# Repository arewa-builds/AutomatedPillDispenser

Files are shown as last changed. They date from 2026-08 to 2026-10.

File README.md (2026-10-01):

# Automated Pill Dispensing & Visual Medication Compliance Monitor

Intelligent, low-cost MedTech station that physically dispenses medication, visually verifies patient presence and pill drop, and tracks adherence risk before missed doses become dangerous.

## Problem

Medication non-adherence costs the healthcare system billions and hits elderly and neurodivergent patients especially hard. This prototype combines a 3D-printed servo carousel, edge computer vision, and Databricks analytics to close that loop non-invasively.

## Architecture

| Layer | Stack | Responsibility |
| :--- | :--- | :--- |
| Embedded | Arduino Nano 33 BLE, MG90S (positional), LiPo + TP4056 | Carousel indexing — 45° per dose, absolute stops |
| Edge CV | Python 3.10+, OpenCV, MediaPipe, PySerial | Face gate + pill contour/color/count |
| Data | Databricks Delta Lake (Bronze → Silver → Gold) | Telemetry ingest & compliance transforms |
| ML / BI | scikit-learn, MLflow, [Databricks dashboard](https://dbc-841e48ce-abec.cloud.databricks.com/dashboardsv3/01f1bc66f608184bb87e728ccb7f308e/published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) | Adherence risk forecast + clinical KPIs |

**Budget:** **$100–$150** (laptop camera preferred) · Timeline **Aug 10 – Sep 20, 2026**.

Published dashboard (SQL warehouse, `pill_dispenser.dashboard_doses` and `pill_dispenser.gold_adherence_7d`): <https://dbc-841e48ce-abec.cloud.databricks.com/dashboardsv3/01f1bc66f608184bb87e728ccb7f308e/published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>

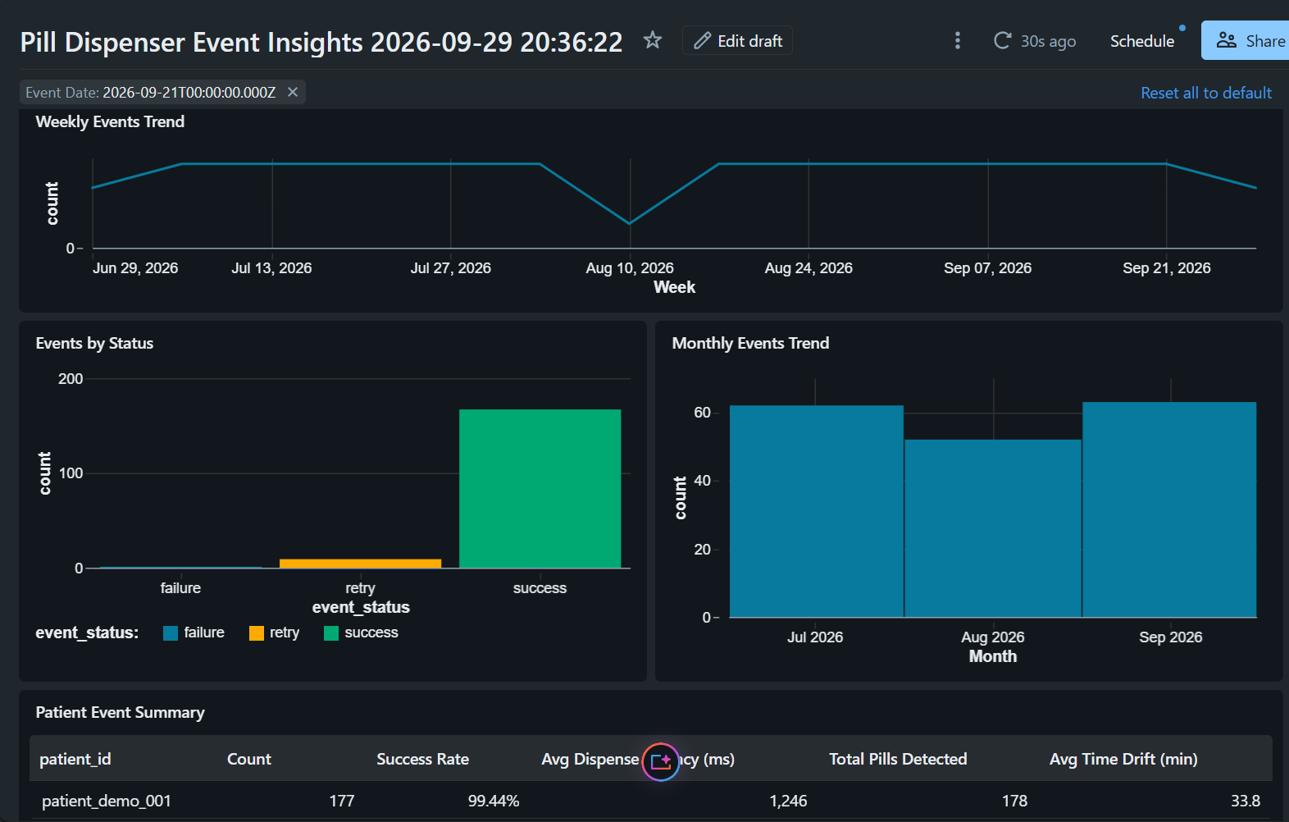
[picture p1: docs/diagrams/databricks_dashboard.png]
Pill Dispenser Event Insights for patient_demo_001: weekly counts dip in the week of 10 Aug, August is lower than July and September, events are mostly success with a few retries, and the summary shows 177 events at 99.44% success


## Repository

```
.cursor/agents/   Expert subagents (systems + CAD)
.cursor/rules/    Always-on project constraints
cad/              OpenSCAD / STL mechanical parts
firmware/         Arduino C++ (Week 1+)
edge/             Python vision + telemetry (Week 2–3)
databricks/       PySpark / Delta Lake (Week 4–5)
ml/               MLflow models (Week 5)
docs/             Schedule, BOM, architecture notes
```

## Cursor expert agents

| Invoke | Role |
| :--- | :--- |
| `/medtech-lead-architect` | Firmware, vision, Databricks, MLflow, Databricks dashboard |
| `/cad-embedded-hardware` | OpenSCAD/STL: carousel, latch, Nano/MG90S/LiPo housing |

See `AGENTS.md` and `cad/README.md`.

## Current status

**Software-first track active** — no Arduino required yet. You can develop vision, mock hardware, telemetry, and local medallion transforms on a laptop now. Firmware is compile-ready for when parts arrive.

## Run now (no hardware)

```bash
# Edge mock pipeline (laptop camera) or headless smoke
cd edge
python3 -m venv .venv; .\.venv\Scripts\Activate.ps1
pip install -r requirements.txt
python pipeline.py --mode mock --headless

# Synthetic Bronze -> Silver -> Gold (local)
cd ../databricks
python3 generate_synthetic_telemetry.py
python3 local_medallion.py
```

See [`docs/software-first-roadmap.md`](docs/software-first-roadmap.md).

## Quick links

- Product brief: [`project.md`](project.md)
- Full schedule & BOM: [`docs/project-context.md`](docs/project-context.md)
- Software-first plan: [`docs/software-first-roadmap.md`](docs/software-first-roadmap.md)
- Edge docs: [`edge/README.md`](edge/README.md)
- Agent guide: [`AGENTS.md`](AGENTS.md)

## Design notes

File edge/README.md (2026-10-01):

# Edge Computer Vision & Telemetry

Python edge stack for face gating, mock/serial dispense, pill verification, and Bronze-ready JSONL logs.

## Docker (project-wide)

From the repo root:

```bash
docker compose build
docker compose run --rm app smoke
docker compose run --rm app edge --mode mock --headless
```

See [`docs/docker.md`](../docs/docker.md). Container installs use `requirements-docker.txt` (`opencv-python-headless`).

## Setup (laptop host venv)

```bash
cd edge
python3 -m venv .venv
# Windows Git Bash: source .venv/Scripts/activate
# Linux/macOS:      source .venv/bin/activate
source .venv/Scripts/activate

# If you previously installed OpenCV 5, remove it first:
pip uninstall -y opencv-python opencv-python-headless opencv-contrib-python

pip install -r requirements.txt
```

Requirements pin **OpenCV 4.x** (`<5`) and **MediaPipe ≥0.10.14**. Face detection uses the **MediaPipe Tasks** BlazeFace model in `models/blaze_face_short_range.tflite` (vendored; auto-downloaded if missing). Avoid OpenCV 5 — it lacks Haar face data and can leave face detection disabled.

## Run without Arduino (recommended now)

```bash
python pipeline.py --mode mock
```

Flow: stable face (MediaPipe Tasks) → mock `DISPENSE` → OpenCV tray pill count → `logs/telemetry/*.jsonl`.

Place candy in the lower-central tray ROI (drawn on screen). Press `q` to quit. A second dose counts when the tray goes from 1 pill to 2; the first pill stays where it landed. The preview spends its first frames on "Camera settling..." so exposure finishes before the face check starts.

If the log shows `FaceGate backend: MediaPipe Tasks`, camera face detection is enabled.

### Headless smoke (CI / no camera UI)

```bash
python pipeline.py --mode mock --headless
```

## Run with Arduino later

Check the drive train on its own first — camera and telemetry out of the way, shaft
out of the carousel hub. Wiring is in
[`docs/diagrams/bench_wiring_3pad.png`](../docs/diagrams/bench_wiring_3pad.png), and the
expected output is in `firmware/README.md`.

```bash
python bench_servo.py --cmd PING          # link only, nothing moves
python bench_servo.py --wiggle            # a few degrees each way, first contact
python bench_servo.py --dump              # one dose at a time: is it exactly one bin?
python bench_servo.py                     # step a whole fill, then rezero
python bench_servo.py --ends              # guided servo endpoint hunt
python bench_servo.py --cmd STATUS        # send anything by hand
```

Then the full loop:

```bash
python pipeline.py --mode serial --port /dev/ttyACM0   # Linux
python pipeline.py --mode serial --port COM3           # Windows
```

## Send each event to Databricks

The pipeline still writes `logs/telemetry/*.jsonl`. When the three variables below are set, it also `INSERT`s that same row into a Bronze table through the SQL Statement Execution API. A warehouse that is down is logged and does not stop the dispense.

Create the table once, in the SQL editor, from `databricks/sql/bronze_dispense_events.sql`. Then copy the example and fill in a new personal access token. The host is the workspace root, with no `/oidc` on the end.

```powershell
copy .env.example .env
# edit .env, then:
python databricks_sink.py          # one test row, patient_id databricks_path_test
python pipeline.py --mode serial --port COM3
```

The insert targets `pill_dispenser.bronze_dispense_events`. With `DATABRICKS_CATALOG` unset, the sink looks up the catalog that holds that table and inserts there. `DATABRICKS_SCHEMA` defaults to `pill_dispenser` and `DATABRICKS_TABLE` defaults to `bronze_dispense_events`. `python databricks_sink.py` sends the latest event already in `logs/telemetry/`. A row landed when the log says `event=databricks_insert_ok`. Query it with:

```sql
SELECT * FROM pill_dispenser.bronze_dispense_events ORDER BY event_ts DESC LIMIT 20;
```

Silver and Gold are not updated by that insert. After a demo, paste `databricks/sql/refresh_silver_gold.sql` into the SQL editor, then refresh the dashboard. The newest Silver rows and the Gold total are the last two results.

## Modules

| File | Role |
| :--- | :--- |
| `face_gate.py` | MediaPipe face presence + stability streak |
| `pill_verify.py` | HSV/contour pill count in tray ROI |
| `hardware_bridge.py` | PySerial bridge with mock fallback |
| `mock_arduino.py` | In-process Nano serial emulator |
| `bench_servo.py` | Bench bring-up: turn check, endpoint hunt, raw commands |
| `telemetry.py` | JSONL event writer, plus the Databricks insert when configured |
| `databricks_sink.py` | One-row INSERT into the Bronze table via the SQL warehouse |
| `pipeline.py` | Orchestration |

Tune HSV / area thresholds in `config.py` for your candy and lighting.

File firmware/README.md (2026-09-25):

# Firmware — Arduino Nano 33 BLE

## Sketch

`pill_dispenser/pill_dispenser.ino` — non-blocking state machine for the v3
mechanism: **one** positional MG90S on D9, driving the carousel directly. There is
no latch servo; the v3 deck parks the just-emptied compartment over the discharge
opening, so nothing sits above it between doses and there is nothing to hold shut.
D10, the v1 latch channel, is free.

Geometry constants are **generated** from `cad/v3/parameters_v3.scad` into
`pill_dispenser/v3_geometry.h` by `tools/geometry_from_cad.sh`, so the sketch and
the CAD cannot drift apart. Re-run that script after changing the carousel pitch,
the deck opening or the hex coupling; the generated header is committed, so
building needs OpenSCAD only when the geometry changes.

| From the CAD | Value | Why the sketch cares |
| :--- | :--- | :--- |
| `STEP_DEG` | 45° | One of 8 compartments (`car_pitch`) |
| `PARK_MARGIN_DEG` | 6.2° | How far off centre park may be before the wedge drains the *next* bin |
| `COUPLING_PLAY_DEG` | 2.58° | The loose hex's rotational play (`hex_backlash`) |

**Everything follows from the park margin.** Three things spend it and the sketch
manages all three.

*Where the horn landed.* The output spline indexes in 17.1° teeth (14.4° on a
25-tooth servo), the hub's hex in 60° and the horn screws in 90°, so assembly alone
can leave the carousel up to 8.6° off centre — more than the margin. Nothing
mechanical adjusts finer, so `TRIM` and `JOG` shift the whole stop table at run
time, with `TRIM_RANGE_DEG` (9°) of authority reserved for them.

*The coupling's play.* The hex is loose so it cannot side-load the carousel, which
costs ±2.58°. A move ends with the driving flats in contact, so the carousel trails
the shaft by that much in whichever direction it last moved; the sketch commands
the shaft that far *past* the stop so the carousel lands *on* it. Reverse a sweep
and the take-up flips sign, which is why `REZERO` ends on a different pulse than a
forward arrival at the same stop.

*The servo's own error*, about a degree, which is what is left.

**Doses per fill is derived, not assumed.** Trim and play have to be reserved at
both ends of the travel, so:

```
DOSES_PER_FILL = (TRAVEL_DEG - 2 * (TRIM_RANGE_DEG + COUPLING_PLAY_DEG)) / STEP_DEG
```

A nominal 180° servo gives **three**. Measure 203° or more — many MG90S reach about
200° between 500 and 2500 µs — and the fourth comes back on its own. After the last
dose `DISPENSE` returns `ERR_MAGAZINE_EMPTY` rather than pushing into the end of the
travel and reporting a dose that never fell. `REZERO` then sweeps back to stop 0,
safe only because the compartments it crosses are the ones it just emptied. The
sketch prints what it derived in its `CAL` banner, so a log always says which it
was.

**Pulse widths, not degrees.** `write()` quantises to 1° (about 10 µs) and pins the
range to the core's 544–2400 µs mapping; this margin can afford neither, so the
sketch commands `writeMicroseconds()` against measured endpoints.

**Ramped, not stepped.** A bare `write()` makes the servo slam the full 45° at
maximum speed: the peak-current case on a small cell, the peak-torque case on a
printed PLA coupling, and the case most likely to overrun a stop on inertia.
`SLEW_DEG_PER_S` (180°/s, so 45° in 250 ms) sets the rate and each move's duration
follows from it, so the timing and the motion cannot disagree. `SETTLE_MS` then
holds the target before the tablet is allowed to move.

## Bench bring-up — wiring and first turns

Nano, servo, one 5 V supply. No carousel yet: run this with the drive shaft **out of
the hub**, or with every bin empty, because a step is a real 45° carousel move and it
will drop whatever sits above the discharge opening.

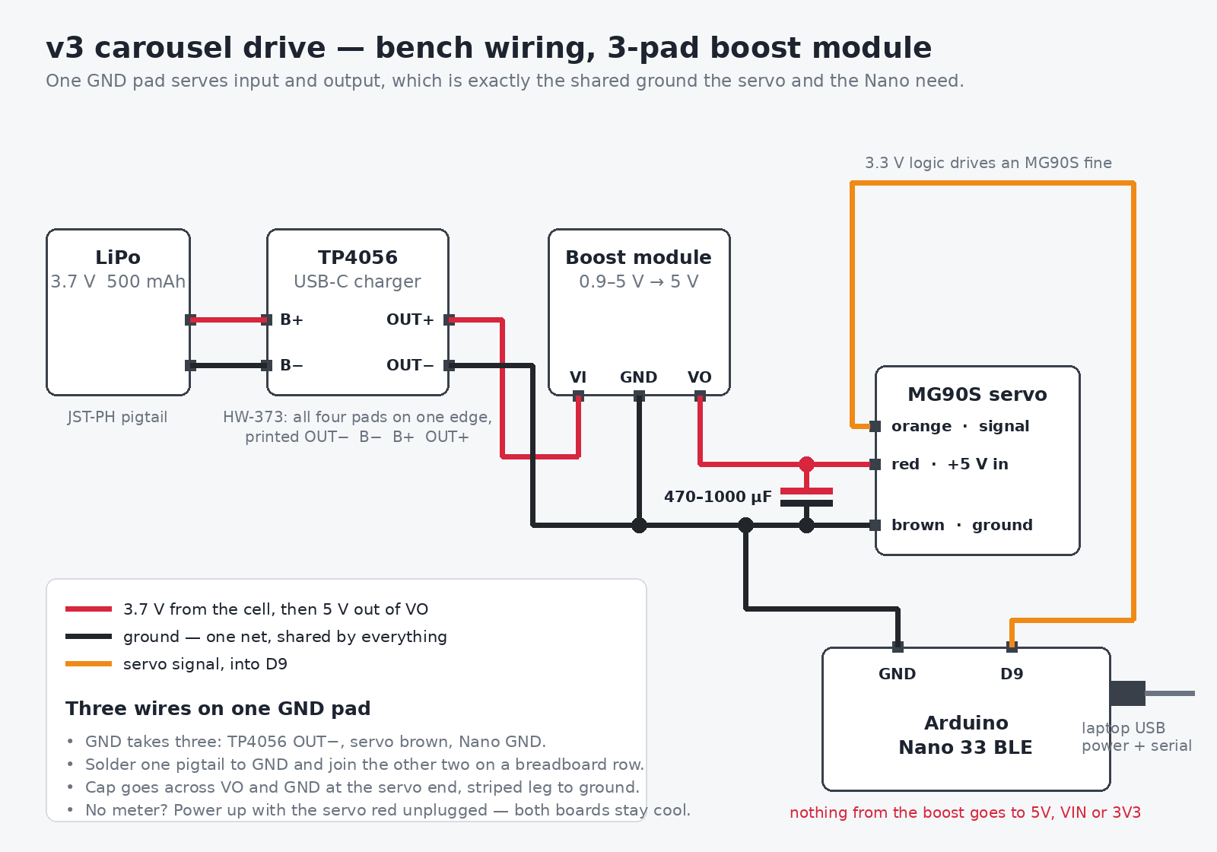
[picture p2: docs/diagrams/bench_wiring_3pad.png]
v3 bench wiring: LiPo through TP4056 and a 3-pad boost module to the MG90S, with the module's single GND shared to the Nano and the signal on D9


Redraw it with `python docs/diagrams/bench_wiring.py` after changing any of this.

| Servo lead | Goes to | Notes |
| :--- | :--- | :--- |
| Orange (signal) | Nano **D9** | 3.3 V logic drives an MG90S fine; if it twitches or ignores commands, put a level shifter on this line |
| Red (V+) | External **5 V**, 1 A or better | A USB breakout, bench supply or power bank — **not** the Nano's 3V3 pin |
| Brown (GND) | Nano **GND** *and* the 5 V supply's ground | The grounds must be common or the pulse has no reference |

### Where the 5 V comes from

The kit's 3.7 V LiPo is below the MG90S's 4.8–6 V rating, so the boost module is what
makes the cell usable. Chain it like this — the cell never touches the servo directly:

```
LiPo JST ──> TP4056 B+/B− ──> TP4056 OUT+ ──> boost VI
                              TP4056 OUT− ──> boost GND ──┬─> servo BROWN
                                                          └─> Nano GND
                                             boost VO  ────> servo RED
```

The cheap boost modules have three pads in one row — `VI`, `GND`, `VO` — with input and
output sharing that single ground, which is the shared node this wants anyway. It takes
three wires: `OUT−` in, servo brown out, Nano `GND` out. Solder one pigtail to the pad
and join the other two on a breadboard row rather than stacking three wires on a pad
that size. On the HW-373 TP4056 all four pads sit along one edge, printed `OUT− B− B+
OUT+`; the cell goes to the `B` pair, never to `OUT`.

The TP4056 is in the chain for its protection circuit, not for charging: a boost module
happily runs down to 0.9 V in and would flatten an unprotected cell past recovery. Even
with it, stop at about 3.4 V rather than waiting for the 2.4 V cutoff.

The Nano keeps its own USB power, which the serial link needs anyway. **Ground is the
only node the two rails share** — nothing from the boost output goes near `3V3`, `5V`
or `VIN`, so a servo brownout cannot reset the board mid-cycle.

These small modules give roughly 500–600 mA at 5 V and an MG90S can pull more than that
against a jam. With a meter, check the output holds above 4.5 V while a step runs. Without
one, the symptoms are the substitute: a stuttering horn, a servo that keeps buzzing after
it arrives, or a Nano that disconnects from USB mid-move all mean the module is sagging —
1000 µF instead of 470 µF, or halve `SLEW_DEG_PER_S` to spread the same move over twice
the time, or run the bench check off a USB power bank and save the LiPo for the untethered
demo.

**No meter.** Read the silkscreen instead of a voltage. On the boost module the cell side
is `VI`, the servo side is `VO`, and `GND` is shared; on the HW-373 the cell is on `B+/B−`
and the boost takes `OUT+/OUT−`. With the servo's red lead still unplugged, power the
chain for a few seconds and touch nothing — the boost module and the TP4056 should stay
cool (warm is fine, hot means a short). Then plug the servo in and start with `--wiggle`:
a few degrees each way is enough to prove the wiring without a reading. A horn that sits
still while the script prints `ACK_PULSE` usually means `VI`/`VO` are swapped, or the
Nano's ground never reached the shared `GND` pad.

Two more things bite here. The Nano 33 BLE's **`5V` pin is disconnected from the factory** —
it only carries USB power once the `VUSB` solder jumper on the underside is bridged —
so treat the servo's supply as external rather than expecting 5 V from the header. And
a stall on a small cell browns the Nano out through the shared ground, which is why the
sketch ramps every move; a 470–1000 µF capacitor across the servo's V+/GND, at the
servo end, absorbs what is left.

```bash
arduino-cli upload -p /dev/ttyACM0 --fqbn arduino:mbed_nano:nano33ble firmware/pill_dispenser
python edge/bench_servo.py --cmd PING     # link only, nothing moves
python edge/bench_servo.py --wiggle       # a few degrees each way, first contact
python edge/bench_servo.py                # the full fill, 45 deg at a time
```

Work up in that order. `--cmd PING` proves the port and the sketch without commanding
the servo at all, `--wiggle` proves the signal and the supply with moves too small to
throw anything, and only then is a full 45° step worth trying.

`edge/bench_servo.py` is the bench harness for exactly this moment. Its default run
greets the board, prints the calibration it derived, then steps a whole fill and
rezeros, timing each move:

```
  calibration: CAL US=600..2400 TRAVEL=180.0 PLAY=2.58 TRIM=0.00 DOSES=3
  step 1: ACK after 991 ms (45 deg from stop 0)
  step 2: ACK after 990 ms (90 deg from stop 0)
  step 3: ACK after 990 ms (135 deg from stop 0)
  step 4: refused, magazine spent — correct after 3 doses
  rezero: ACK after 1100 ms — shaft should be back on the mark
```

Mark the horn before you start. Each `ACK_DISPENSE` is one bin, so three steps is 135°
of carousel and `REZERO` should bring the mark back where it began. A mark that does
not return means the coupling is slipping on the horn, not a firmware problem. Other
modes: `--wiggle` for first contact, `--ends` for the guided endpoint hunt below,
`--sweep 600 2400 --step 200` to walk raw pulses, `--cmd "TRIM 3"` to send anything by
hand, `--list` for the ports.

## Commissioning a servo

Do this once per servo, with the carousel empty. It replaces four constants at the
top of the sketch and one runtime trim.

1. **Find the ends.** `PULSE <us>` commands a raw pulse anywhere in 500–2500 µs, which
   is wider than the calibrated ends on purpose: finding them is the point.
   `python edge/bench_servo.py --ends` creeps outward from 1500 µs in 100 µs steps and
   asks, after each one, whether the horn moved further the same way. `y` continues,
   `n` means it only buzzed in place (that is the stop), and `q` means it jumped back
   the other way, which is the pulse going past the feedback pot — the hunt stops
   there rather than stripping the gears. Enter by
   itself is ignored, because holding it down used to run into the 500–2500 µs envelope
   and print those limits as if they were the stops. It backs off 50 µs from the last
   pulse that moved and, if you type both dial readings, prints `TRAVEL_DEG` and whether
   that is three doses or four. Put the two pulses in `US_MIN_SAFE` / `US_MAX_SAFE`.
2. **Measure the travel.** Print [`docs/diagrams/servo_protractor.png`](../docs/diagrams/servo_protractor.png)
   at 100%, cut its centre out, slip it over the horn screw and tape a toothpick along
   the horn. Read the pointer at each end; the difference is `TRAVEL_DEG`. The dial marks
   203° in blue because that is the threshold where a fill gives four doses instead of
   three, and its red ticks are the carousel's 45° bin pitch, so one `DISPENSE` should
   move the pointer exactly one tick. Recompile after setting it: the sketch reports the
   doses per fill it derives, and its `static_assert`s refuse a table that will not fit.

   No printer? The carousel is its own protractor — eight dividers at 45°. Sweep end to
   end with it loosely on the shaft and count: more than four and a half bin pitches
   means you have the 203°.
3. **Check each dose is one bin.** `python edge/bench_servo.py --dump` rezeros,
   then dispenses one dose at a time and waits. The carousel must advance 45° per
   dose. The horn moves 45° plus twice the coupling play on the first dose — the
   shaft takes the play up from the reverse side the rezero left it on — and 45°
   after that. Type the dial reading after each dose and it reports the error
   against a ±2° band. Three doses each 3° short land on the next compartment,
   which is why the band is tighter than the ±6.2° park margin.

   A step that is short or long by the same amount every time is the pulse scale,
   not the park: finish step 2 and set `TRAVEL_DEG`. `JOG` only recentres the park.
   With the carousel fitted and one compartment filled, `JOG 2` / `JOG -2` until
   the just-emptied compartment sits over the opening. `STATUS` shows the trim.
4. **Record it.** The trim lives in RAM. Log the value and have the host send
   `TRIM <deg>` on connect, or paste it into `PARK_TRIM_DEG`'s default and
   recompile.

## Serial protocol @ 115200

A superset of the v1 protocol, so hosts that only speak `DISPENSE` /
`ACK_DISPENSE` — including `edge/hardware_bridge.py` — need no changes.

| Host sends | Device replies | Notes |
| :--- | :--- | :--- |
| `DISPENSE` | `ACK_DISPENSE` | About 1 s: 270 ms ramp, 120 ms settle, 600 ms for the dose to reach the tray |
| | `ERR_BUSY` | Mid-cycle |
| | `ERR_MAGAZINE_EMPTY` | Last stop reached; refill and `REZERO` |
| `REZERO` | `ACK_REZERO` | Ramps back to stop 0; duration follows the distance |
| `SETSTOP n` | `ACK_SETSTOP` / `ERR_ARG` | Corrects the sketch's count **without moving** |
| `TRIM d` | `ACK_TRIM <deg>` / `ERR_ARG` | Sets the park offset, ±9°, and re-seats the carousel on its stop |
| `JOG d` | `ACK_TRIM <deg>` / `ERR_ARG` | Same, relative to the trim in force |
| `PULSE us` | `ACK_PULSE <us>` / `ERR_ARG` / `ERR_BUSY` | Commissioning: ramps to a raw pulse in 500–2500 µs, then marks the magazine spent so no `DISPENSE` can follow a hand-jogged position |
| `STATUS` | `STATE=s STOP=i/n ANGLE=d US=u TRIM=t DOSES=n` | |
| `CAL` | `CAL US=a..b TRAVEL=t PLAY=p TRIM=t DOSES=n` | Also printed at boot |
| `PING` | `PONG` | |

`TRIM` and `JOG` answer only once the carousel has settled on its stop, so the
reply means the offset is in effect rather than merely accepted.

The servo holds its angle mechanically when unpowered, so the carousel's position
survives a power cycle but the sketch's idea of it does not. On boot it assumes
stop 0 and deliberately commands no angle — writing one could sweep full
compartments across the opening and dump them. A host that logged the doses can
correct the count with `SETSTOP`.

## Check the behaviour without a board

```bash
./firmware/test/run.sh
```

Compiles the sketch on the host against small stubs — fake clock, fake serial,
recording servo — and drives it through every dose of a fill and the refusal after
them, the ramp (monotonic, starting where it believed it was, ending on the pulse
the park budget calls for), the play take-up flipping sign on a reverse sweep,
`TRIM`/`JOG` authority and bounds, `PULSE` reaching past the calibrated ends and
locking out `DISPENSE` until the stop is re-established, and a sweep proving no pulse
in normal operation left the servo's measured ends. 65 checks, needs only `g++`. See
`firmware/test/host_harness.cpp`.

This complements the toolchain check below rather than replacing it: one proves
the logic, the other proves it builds for the real target.

## Check Arduino IDE / toolchain without a board

You do **not** need the Nano plugged in to confirm the IDE/toolchain works. Compile (Verify) only:

**Option A — Arduino IDE GUI**

1. Install board pack: *Tools → Board → Boards Manager → “Arduino Mbed OS Nano Boards”*
2. Install library: *Tools → Manage Libraries → Servo*
3. Open `pill_dispenser/pill_dispenser.ino`
4. Select board: **Arduino Nano 33 BLE**
5. Click **Verify** (✓) — not Upload

**Option B — script (`arduino-cli`)**

```bash
# Linux / macOS / WSL
chmod +x firmware/verify_arduino_toolchain.sh
./firmware/verify_arduino_toolchain.sh
```

```powershell
# Windows PowerShell
.\firmware\verify_arduino_toolchain.ps1
```

Success means `Servo.h` resolved and the sketch built for `arduino:mbed_nano:nano33ble`.

## Upload later (board connected)

```bash
arduino-cli board list
arduino-cli upload -p /dev/ttyACM0 --fqbn arduino:mbed_nano:nano33ble firmware/pill_dispenser
```

Windows: use `COM3` (or your port) instead of `/dev/ttyACM0`.

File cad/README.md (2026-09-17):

# CAD — Full Printable Prototype Set

Parametric **OpenSCAD** sources, **STL** meshes, and **PNG** previews for an adequate Automated Pill Dispenser mechanical prototype.

> **Which set to print** — the files in this directory are **v1**, the set that was
> printed and assembled first. Its bench failures (servo blocked by internal ribs,
> drop plate rotating instead of the carousel, slit-sized chute exit) are fixed in
> [`v2/`](v2/README.md): cylindrical drum, keyed fixed plate with one opening, open
> carousel driven directly from above, 40 mm wide 45 deg chute. STLs are exported
> and ready to slice.
>
> [`v3/`](v3/README.md) is the current design direction, modelled from a newer
> reference drawing: the deck is integral to the housing so no plate can rotate,
> the 8 compartments are open bins, the chute is part of the housing, and the servo
> hangs from a single L bracket. Geometry and previews are done; STL export is
> pending sign-off (see [`v3/PLAN.md`](v3/PLAN.md)).

## Expert agent

`/cad-embedded-hardware` — refine fits, regenerate parts, adjust clearances.

## Explore the full assembly

1. Install [OpenSCAD](https://openscad.org/).
2. Open `assembly_preview.scad` → **F5**.
3. Toggle `EXPLODED = true/false`.

Or browse screenshots in `previews/`.

## Print bill of materials (3D parts)

| ID | File | Qty | Purpose |
| :--- | :--- | ---: | :--- |
| **A** | `part_a_base_enclosure.scad` | 1 | Main housing: Nano, LiPo/TP4056, carousel servo, chute |
| **B** | `part_b_base_plate.scad` | 1 | Drop floor with 20×15 mm hole + latch rails |
| **C** | `part_c_carousel.scad` | 1 | 8-pocket carousel + MG90S horn hub |
| **D** | `part_d_latch_gate.scad` | 1 + 1 | Separate STLs: `part_d_latch_gate.stl`, `part_d_latch_horn_arm.stl` |
| **E** | `part_e_carousel_lid.scad` | 1 | Lid / finger shield / anti-spill |
| **F** | `part_f_catch_tray.scad` | 1 | Vision landing tray (OpenCV ROI) |
| **G** | `part_g_chute_spout.scad` | 1 | Chute → tray guide |
| **H** | `part_h_latch_servo_bracket.scad` | 1 | Second MG90S mount for latch |
| **I** | `part_i_cable_clips.scad` | print **4×** | Single-body `part_i_cable_clip.stl` (duplicate in slicer) |
| **J** | `part_j_feet.scad` | print **4×** | Single-body `part_j_foot.stl` (duplicate in slicer) |
| **K** | `part_k_pill_insert.scad` | 0–8 | Optional pocket reducers for small tablets |

Parts **D / I / J** no longer ship multi-body “floating plate” STLs — one solid per file.

Shared dimensions: `parameters.scad`.

### Not printed (buy / reuse)

- Arduino Nano 33 BLE, 2× MG90S, LiPo 500 mAh, TP4056  
- M2/M2.5 screws, wire, **5V servo supply + common ground**  
- Laptop camera (index 0)  
- Homing sensor — **optional** for v1 (manual pocket #0 alignment)

## Regenerate STLs + PNGs

```bash
chmod +x cad/render_all.sh
./cad/render_all.sh
```

Manual: open a part → **F6** → **File → Export → STL** into `cad/stl/`.

## Suggested print settings

- PLA (or PETG for latch/gate), **0.4 mm** nozzle, **0.2 mm** layers  
- 3–4 perimeters, 20–30% infill (40% for carousel hub)  
- Supports: light under Part A chute underside and Part G channel if printed flat  

## Assembly order

1. J feet under A  
2. Carousel MG90S into A well; press C onto horn; seat B plate  
3. H bracket + latch MG90S; fit D gate into B rails; link D arm  
4. E lid on C  
5. G spout on A chute exit → F catch tray in front  
6. I clips on USB / servo leads  
7. K inserts only if tablets rattle in full-size pockets  

Firmware pins: carousel **D9**, latch **D10**.

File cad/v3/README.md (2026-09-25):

# v3 CAD set — integral deck, 8 open compartments, one servo

The design in [`reference_design.png`](reference_design.png), modelled. All seven
parts plus three test coupons are exported to `stl/`, each watertight and each in
its print orientation. **Print the coupons first** — about 90 minutes that
de-risks 24 hours of printing. See `PLAN.md` section 8.

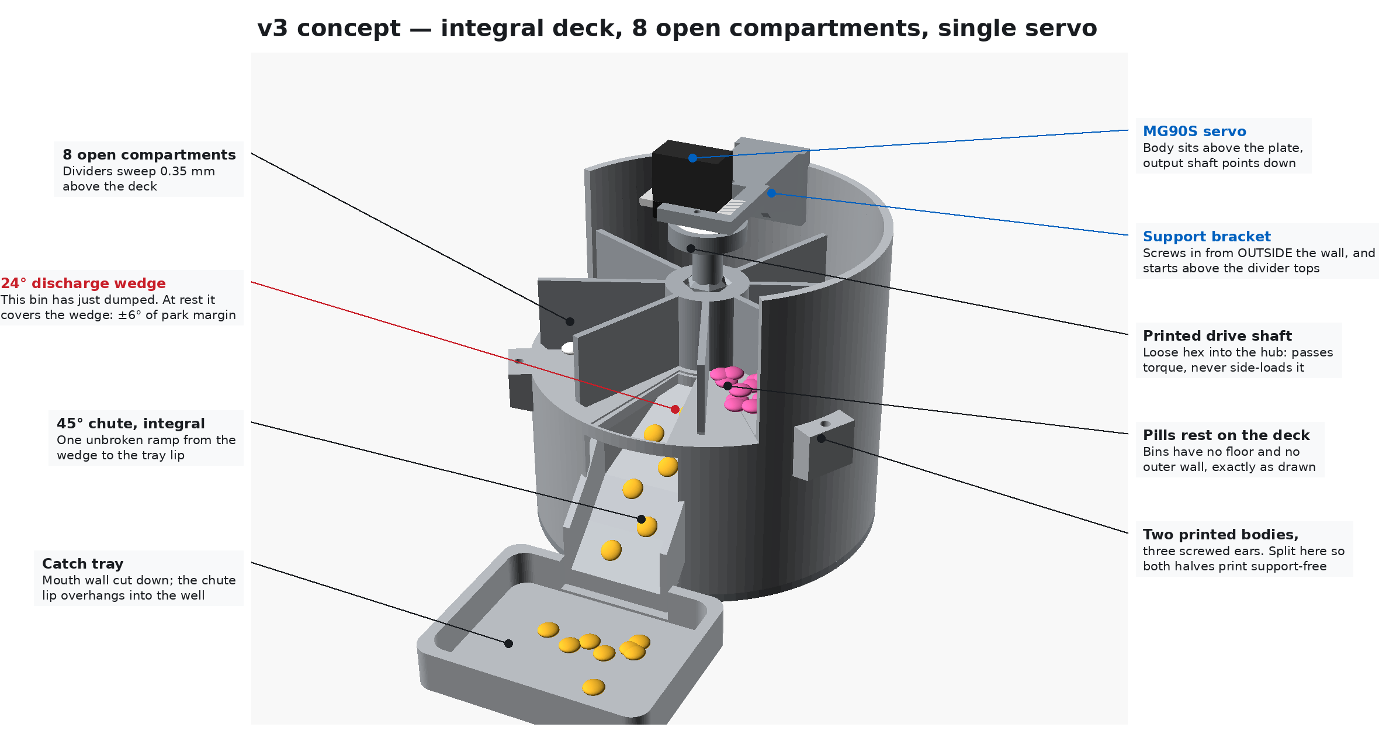
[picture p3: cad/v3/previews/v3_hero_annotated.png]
v3 annotated


## How it dispenses

The deck holds the pills in — the compartments have no floor and no outer wall,
so the deck below and the drum bore around them do the containing. The deck has
one 24 deg wedge opening over the chute. At rest, the compartment that has just
been emptied sits centred on that wedge, so there is nothing above the opening to
fall through. Advancing 45 deg sweeps the next compartment across the wedge and
gravity empties it down the chute into the tray.

The opening is 24 deg and a compartment's interior is 36.4 deg at that radius, so
there is **+/- 6.2 deg of parking margin**. That is the number the whole design
turns on: `parameters_v3.scad` derives it and every part echoes it. Park further
off than that and the wedge starts draining the next compartment, which is why v3
wants a positional servo rather than a continuous-rotation one.

Turning it is easy — an MG90S has roughly 6x the torque this needs, so the error
budget, not the muscle, is what the drive train is designed around. A step ends
with the coupling's driving flats in contact, so the carousel parks behind its stop
by the full hex play; that is why the hex is 12 mm across flats rather than 7 mm,
which holds the play to ±2.58° instead of ±6.28° at the same easy fit. PLAN.md
section 13 carries the torque and error budget in full.

From the wedge on, the tablet is on its own until it reaches the tray, so the ramp
has to be unbroken the whole way.

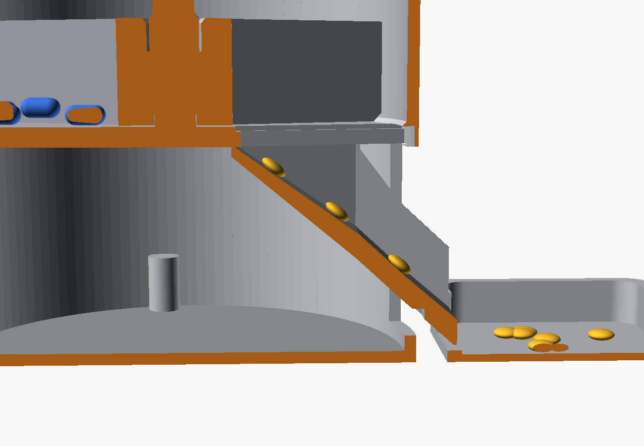
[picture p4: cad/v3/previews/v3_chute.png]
chute section


It starts at y = 14 — inside the wedge's 16 mm
inner radius, so a tablet always lands on ramp rather than on its leading edge —
and the notch through the drum wall is cut as a box *minus the chute solid*, which
means retuning the chute can only ever remove housing wall, never floor. Open
`check_drop_path.scad` and look straight down to confirm it: the wedge footprint
must be filled edge to edge, because everything else under the wedge is cut away,
so anything visible there is ramp and any daylight is a hole.

The other thing that has to hold is that the carousel can actually turn. Radial
dividers sweep a whole solid ring — z 57.35 to 83.35, hub out to r 56.3 — so
anything bolted down that reaches into it is a dead stop, not a tight fit. The
bracket's pad and gusset are therefore derived off the divider tops rather than
typed in, and the wall runs up to z 106 so both bracket screws land in wall that is
above the sweep. `check_carousel_clearance.scad` proves it on the geometry: modes 0
and 2 must render nothing, mode 1 only the pilot post, mode 3 only the shaft's hex
foot.

## Files

| File | What |
| :--- | :--- |
| `parameters_v3.scad` | every dimension, plus the derived park margin |
| `lib_v3.scad` | sector/ring/tube helpers |
| `part_a3_deck_body.scad` | drum wall + integral deck + wedge + pilot post |
| `part_b3_base_body.scad` | bay + integral 45 deg chute + wall notch |
| `part_c3_carousel.scad` | hub + 8 dividers |
| `part_d3_drive_shaft.scad` | printed shaft extension, horn pocket to hex foot |
| `part_e3_servo_bracket.scad` | L bracket for the MG90S |
| `part_f3_catch_tray.scad` | tray, mouth flush to the chute lip |
| `part_g3_base_cover.scad` | electronics floor |
| `assembly_preview_v3.scad` | preview only — flags at the top of the file |
| `check_drop_path.scad` | proves the ramp is continuous under the wedge |
| `check_carousel_clearance.scad` | proves nothing fixed sits in the carousel's path |
| `coupon_1_sector.scad` | deck + carousel sectors: running gap, sweep gap |
| `coupon_2_drive_train.scad` | servo plate, shaft, hub socket: the three fits |
| `coupon_3_chute_dock.scad` | chute lip + tray mouth: the dock |
| `render_all_v3.sh` | previews by default, `--stl` also exports STLs |

Each part module works in assembly coordinates, and each file's top-level call
applies that part's print orientation. So `stl/` loads onto the bed ready to slice
— don't re-orient it — while the preview still shows every part where it sits.

## Renders

```bash
sudo apt-get install -y openscad          # once
pip install pillow                        # for the annotated hero only
./render_all_v3.sh                        # previews -> previews/
./render_all_v3.sh --stl                  # previews + stl/
```

Assembly views:

| View | |
| :--- | :--- |
| `previews/v3_hero_annotated.png` | cutaway with callouts |
| `previews/v3_cutaway.png` | wall cut away over the chute |
| `previews/v3_assembled.png` | as it sits on the desk |
| `previews/v3_section.png` | half section: deck, running gap, chute, drive train |
| `previews/v3_chute.png` | same section, closed in: the ramp unbroken from the wedge to the lip |
| `previews/v3_drop_path.png` | the fall volume ghosted over the base body — `check_drop_path.scad` |
| `previews/v3_top.png` | 8 bins and the discharge wedge |
| `previews/v3_exploded.png` | assembly order |

One view per part, plus two details worth their own frame:

| View | |
| :--- | :--- |
| `previews/part_a3_deck_body.png` | wedge, pilot post, bracket screw seats, joint ears |
| `previews/part_a3_deck_body_deck_wedge.png` | straight down the deck: the 24 deg wedge |
| `previews/part_b3_base_body.png` | bay, chute, cover posts |
| `previews/part_b3_base_body_chute.png` | the continuous ramp through the wall notch, and the shoulder fins |
| `previews/part_c3_carousel.png` | hub and 8 dividers |
| `previews/part_d3_drive_shaft.png` | head down |
| `previews/part_e3_servo_bracket.png` | MG90S pocket, gusset, ribs — flipped, flange plane on the bed |
| `previews/part_f3_catch_tray.png` | cut-down mouth wall |
| `previews/part_g3_base_cover.png` | electronics floor |
| `previews/coupon_1_sector.png` | C1, both sectors nested on the bed |
| `previews/coupon_2_drive_train.png` | C2, plate pad + shaft + hub puck |
| `previews/coupon_3_chute_dock.png` | C3, chute exit + tray mouth |

Blue faces are outside surfaces, orange faces are cut surfaces — the same
convention as the v1 and v2 preview sets.

Preview flags: `CUTAWAY`, `SECTION`, `EXPLODED`, `SHOW_PILLS`, `SHOW_BRACKET`,
and `DOSE_ANGLE` (22.5 = at rest with the emptied bin over the wedge).

## Assembly order

1. Screw the round horn into the **drive shaft** head (4x M2).
2. Drop the **carousel** into the **deck body**, hub onto the pilot post.
3. Drop the shaft's hex foot into the hub socket. It should drop in under its own
   weight — that looseness is intentional, so the shaft passes torque without
   side-loading the carousel — but it should not rock more than about 2.5°, since
   that play is what the park margin has to absorb.
4. Bolt the **bracket** to the wall with 2x M3 driven in from *outside* the drum.
5. Push the **MG90S** down through the bracket's plate onto the horn's spline,
   then 2x M2 through the flange.
6. Mount the electronics on the **base cover**, screw it into the **base body**'s
   three posts, route the cable through the rear port.
7. Stack the deck body on the base body and screw the three ears together.
8. Butt the **tray** up to the chute lip.

To refill or service: take out 2 bracket screws, lift the bracket, servo and
shaft off as one unit, and the carousel lifts straight out of a clear 114 mm bore.

## Differences from v2

v2 is the printable "fix the v1 failures" set: separate keyed plate, holed and
ramped carousel floor, four-arm servo spider, separate chute insert. v3 follows
the newer reference drawing instead: the deck is integral to the housing (so no
plate can rotate), the compartments are open bins, the chute is part of the
housing, and the servo hangs from a single L bracket. Fewer parts, fewer
interfaces, and it needs a positional servo where v2 tolerated a sloppier one.

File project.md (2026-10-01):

The purpose of this project is to build
Automated Pill Dispensing & Visual Medication Compliance Monitor
An intelligent, 3D-printed pill station that physically dispenses medication, visually verifies pill type and patient identity via CV, and tracks compliance patterns to prevent dangerous missed doses.

The Problem: Non-adherence to medication costs the healthcare system billions and severely impacts elderly or neurodivergent patients.

Hardware Rig ($100–$150):

3D-printed continuous-rotation or servo-driven carousel dispenser connected to an Arduino.

USB Webcam pointed at the dispensing tray.

Computer Vision (Python Edge):

Uses MediaPipe Face Mesh / facial detection to verify the correct patient is at the dispenser.

Employs an OpenCV contour and color classification pipeline to visually confirm that the correct pill size, color, and count reached the tray. The v3 mechanism has no latch to gate — the carousel's park position holds the remaining doses back — so this check confirms the dose that just fell and flags a miss rather than authorising the drop.

Databricks Integration:

Data Lake Pipeline: Logs every successful dispense, facial match confidence score, and time-to-ingestion latency into Delta Lake.

Predictive ML: Uses MLflow to model "Adherence Risk." The model detects subtle shifts in dispense timing (e.g., patient taking meds later and later each day) to alert caregivers before a complete missed dose occurs.

Storytelling Focus: Patient Safety, MedTech Automation, and Non-Invasive Caregiving.

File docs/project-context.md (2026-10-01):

# Project Context — Schedule, Resources & Budget

**Project:** Automated Pill Dispensing & Visual Medication Compliance Monitor  
**Timeline:** August 10 – September 20, 2026 (6 weeks)  
**Budget target:** **$100–$150 USD**

## 1. Resource & Cost List

### Hardware & Physical Components

| Item | Specification / Purpose | Estimated Cost (USD) |
| :--- | :--- | ---: |
| Microcontroller | Arduino Nano 33 BLE (BLE & sensor onboard) | $26.00 |
| Actuators | MG90S Metal-Gear Micro Servos, **positional** (2-pack; the v3 mechanism drives the carousel with one and keeps the other as a spare) | $12.00 |
| Camera | Built-in laptop camera (preferred) **or** 1080p USB Webcam / ESP32-CAM | $0.00 – $20.00 |
| Power Supply | 3.7V 500mAh LiPo + USB-C TP4056 charger + 0.9–5V→5V boost module. The MG90S is rated 4.8–6 V and the bare cell sits under that, so the servo runs off the boost output (LiPo → TP4056 B+/B− for its protection circuit → OUT+ to boost VI → boost VO to servo red, boost GND shared with the Nano) with a 470–1000 µF bulk cap across it. The Nano keeps USB power; ground is the only shared node. Wiring diagram: `docs/diagrams/bench_wiring_3pad.png` | $10.00 |
| Enclosure & Frame | 3D Printable Filament (PLA/PETG) / Hardware fasteners | $15.00 |
| Prototyping Essentials | Breadboard, jumper wires, resistors, calibration pills/candies | $10.00 |
| **Subtotal Hardware** | | **$73.00 – $93.00** |

### Software, Cloud & Tools

| Service / Tool | Tier & Usage | Estimated Cost (USD) |
| :--- | :--- | ---: |
| Python Ecosystem | Local Python 3.10+, OpenCV, MediaPipe, PySerial (Open-Source) | $0.00 |
| Arduino IDE | Desktop C++ compiler and library manager | $0.00 |
| Databricks Environment | Community Edition **or** Standard 14-day Free Trial + micro-VM fees | $0.00 – $15.00 |
| Databricks dashboard | Included with the Databricks workspace. Published at <https://dbc-841e48ce-abec.cloud.databricks.com/dashboardsv3/01f1bc66f608184bb87e728ccb7f308e/published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>. Reads `pill_dispenser.dashboard_doses` and `pill_dispenser.gold_adherence_7d`. | $0.00 |
| **Subtotal Software/Cloud** | | **$0.00 – $15.00** |

**Project cost: $100–$150 USD.** The table above is the component list. The project range covers those parts plus shipping, tax, and spares. The laptop camera keeps the camera line at $0.

## 2. Detailed 6-Week Execution Schedule

### Week 1: Physical Prototype & Microcontroller Firmware
**Focus:** Assembling the physical mechanism and proving local servo control.  
**Days 1–2:** Source hardware; download or modify open-source carousel STL files for 3D printing.  
**Days 3–4:** Flash Arduino Nano 33 BLE. Write C++ firmware for MG90S indexing — absolute 45° stops, no latch; the v3 deck's park convention replaces it.  
**Days 5–7:** Wire LiPo + TP4056 + boost module; bench-check the turns with `edge/bench_servo.py`. Test dispensing repeatability with candy/dummy pills over Serial.  
**Milestone 1:** Reliable physical dispenser that drops a single pill on command.

### Week 2: Edge Computer Vision Engine (Python)
**Focus:** Local vision verification for patient identity and pill count.  
**Days 8–10:** Set up `opencv-python`, `mediapipe`. Aim camera at dispensing tray.  
**Days 11–12:** MediaPipe Face Detection — require user presence before dispense.  
**Days 13–14:** OpenCV contour/color/size pipeline to count pills on the tray.  
**Milestone 2:** Face detect → release command → visual pill confirm in under 2 seconds.

### Week 3: Edge-Hardware Integration & Telemetry Pipeline
**Focus:** Link vision logic with Arduino; format JSON logs.  
**Days 15–17:** Connect via BLE or Serial (`PySerial`).  
**Days 18–19:** Standardize telemetry JSON (`timestamp`, `patient_id`, `face_match_confidence`, `pills_detected`, `dispense_latency_ms`).  
**Days 20–21:** Retry loops if no pill is visually detected after actuation.  
**Milestone 3:** Integrated edge system generating structured JSON per dispensing cycle.

### Week 4: Databricks Pipeline Development (Bronze & Silver)
**Focus:** Ingest telemetry into Delta Lake via PySpark.  
**Days 22–24:** Launch workspace; Bronze ingest of JSON payloads. The edge sink inserts each live event directly (`edge/databricks_sink.py` → `pill_dispenser.bronze_dispense_events`, in the catalog that holds that table); the local medallion remains the offline stand-in.  
**Days 25–27:** Silver — clean timestamps, compliance deltas vs schedule, dedupe hardware pings.  
**Milestone 4:** Automated Bronze → Silver transforms.

### Week 5: Machine Learning & Risk Forecasting (Gold & MLflow)
**Focus:** Anomaly / adherence risk prediction.  
**Days 28–30:** Gold aggregations (7-day adherence, average time drift).  
**Days 31–33:** Train sklearn model; track in MLflow (progressive later dosing → risk).  
**Day 34:** Databricks alerts for High Adherence Risk.  
**Milestone 5:** Model forecasting non-adherence from telemetry.

### Week 6: Databricks Dashboard & Final Integration Testing
**Focus:** Databricks dashboard, E2E tests, documentation.  
**Days 35–37:** Databricks dashboard on the SQL warehouse, over `pill_dispenser.dashboard_doses` and `pill_dispenser.gold_adherence_7d`; clinical KPIs. Published: <https://dbc-841e48ce-abec.cloud.databricks.com/dashboardsv3/01f1bc66f608184bb87e728ccb7f308e/published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>.  
**Days 38–40:** Full E2E (Hardware → Vision → Databricks → ML → Dashboard).  
**Days 41–42:** Architecture diagrams, repo cleanup, build videos.  
**Milestone 6:** Demo-ready cloud-connected MedTech prototype.

## 3. Laptop Camera Notes

OpenCV selects the built-in camera with index `0`:

```python
import cv2

cap = cv2.VideoCapture(0)
```

**Practical tips**
- Place the tray on the desk in front of the keyboard; tilt the laptop screen so the lens sees the tray.
- Sequential workflow: detect face looking at the screen, then verify the pill drop on the tray.
- Skipping a USB webcam saves ~$20 on the BOM.

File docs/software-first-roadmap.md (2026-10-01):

# Software-First Roadmap (No Hardware Purchased Yet)

You can complete a large share of Weeks 2–5 before the Arduino kit arrives. Use your **laptop camera (index 0)** and a **mock serial dispenser**.

## Do now (highest ROI)

| Priority | Workstream | Needs hardware? | Outcome |
| ---: | :--- | :---: | :--- |
| 1 | MediaPipe face presence gate | No (laptop cam) | Week 2 face milestone |
| 2 | OpenCV pill count on candy/dummy pills | No (laptop cam + candy) | Week 2 pill verify |
| 3 | Mock Arduino + Serial command protocol | No | Week 3 integration without board |
| 4 | Telemetry JSON contract + local log writer | No | Feeds Week 4 Bronze |
| 5 | Compile-ready Nano 33 BLE firmware | No (flash later) | Week 1 code ready on day parts arrive |
| 6 | Synthetic Bronze → Silver transforms | No | Week 4 pipeline logic |
| 7 | Synthetic adherence drift → MLflow baseline | No | Week 5 model skeleton |

## Defer until parts arrive

- Physical servo tuning / PWM pulse calibration  
- LiPo + TP4056 wiring validation  
- Real BLE pairing on Nano 33 BLE  
- Dispense repeatability with the 3D-printed carousel  

## Suggested daily loop (pre-purchase)

1. Run the containerized smoke test: `docker compose run --rm app smoke` (or host `edge/pipeline.py --mode mock`).  
2. Tune HSV/contour thresholds for your candy under desk lighting.  
3. Review `firmware/pill_dispenser/pill_dispenser.ino` pin map against the BOM you will order.  
4. Generate a week of synthetic telemetry: `docker compose run --rm medallion`.  

## Parts order (when ready)

See BOM in `docs/project-context.md`. Prefer the **laptop camera** so the build stays inside the **$100–$150** project cost.

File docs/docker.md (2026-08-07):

# Docker Guide — Automated Pill Dispenser

Run the software-first stack (edge mock pipeline + local medallion) in a single container image. Firmware source is included in the image for reference; flashing the Nano 33 BLE still happens on the host via Arduino IDE / `arduino-cli`.

## Prerequisites

- Docker Engine 24+ and Docker Compose v2+
- Optional (camera profile): Linux host with `/dev/video0`
- Optional (serial profile): Arduino on `/dev/ttyACM0`

## Quick start

```bash
# Build the image
docker compose build

# Headless mock edge smoke (no camera / no Arduino)
docker compose run --rm app smoke

# Synthetic Bronze → Silver → Gold
docker compose run --rm medallion

# Help
docker compose run --rm app help
```

Artifacts land on the host via bind mounts:

| Host path | Container path |
| :--- | :--- |
| `edge/logs/` | `/app/edge/logs` |
| `databricks/sample_data/` | `/app/databricks/sample_data` |

## Services & profiles

| Service | Profile | Purpose |
| :--- | :--- | :--- |
| `app` | (default) | Edge mock headless smoke |
| `medallion` | (default) | Generate telemetry + local medallion |
| `shell` | `dev` | Interactive bash with repo mounted |
| `edge-camera` | `camera` | Mock edge with `/dev/video0` passthrough |
| `edge-serial` | `serial` | Real Arduino serial on `/dev/ttyACM0` |

```bash
docker compose run --rm medallion
docker compose --profile dev run --rm shell
docker compose --profile camera run --rm edge-camera
docker compose --profile serial run --rm edge-serial
```

## Entrypoint commands

The image entrypoint (`docker/entrypoint.sh`) accepts:

```text
smoke | edge | medallion | generate-telemetry | shell | python | help
```

Examples:

```bash
docker compose run --rm app edge --mode mock --headless --cycles 1
docker compose run --rm app python -c "import cv2, mediapipe; print(cv2.__version__)"
docker compose run --rm app shell
```

## Camera & GUI notes

- **Default container path is headless** (`opencv-python-headless`) — use `--headless` or the `smoke` command.
- For interactive `cv2.imshow` face/tray UI, run the host venv on your laptop (`edge/README.md`). X11-forwarding into Docker is possible but brittle across macOS/Windows.
- Linux camera passthrough:

```bash
docker compose --profile camera run --rm edge-camera
```

## Arduino serial (when hardware arrives)

```bash
# Confirm device on host first: ls /dev/ttyACM*
docker compose --profile serial run --rm edge-serial
```

If the device path differs, override:

```bash
docker compose run --rm --device=/dev/ttyUSB0:/dev/ttyACM0 app \
  edge --mode serial --port /dev/ttyACM0 --headless
```

## Image layout

```text
/app
  edge/           Python vision + telemetry
  databricks/     Local medallion scripts + sample_data
  firmware/       Arduino source (flash from host)
  docs/           Project docs
```

## Rebuild after code changes

```bash
docker compose build --no-cache
docker compose run --rm app smoke
```

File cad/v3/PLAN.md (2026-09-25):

# v3 STL plan — "integral deck + open carousel"

Plan of record for the v3 reference design. The OpenSCAD sources in this folder
implement it and render clean; **STL export is deliberately not run yet** — see
section 9 for the remaining gates.

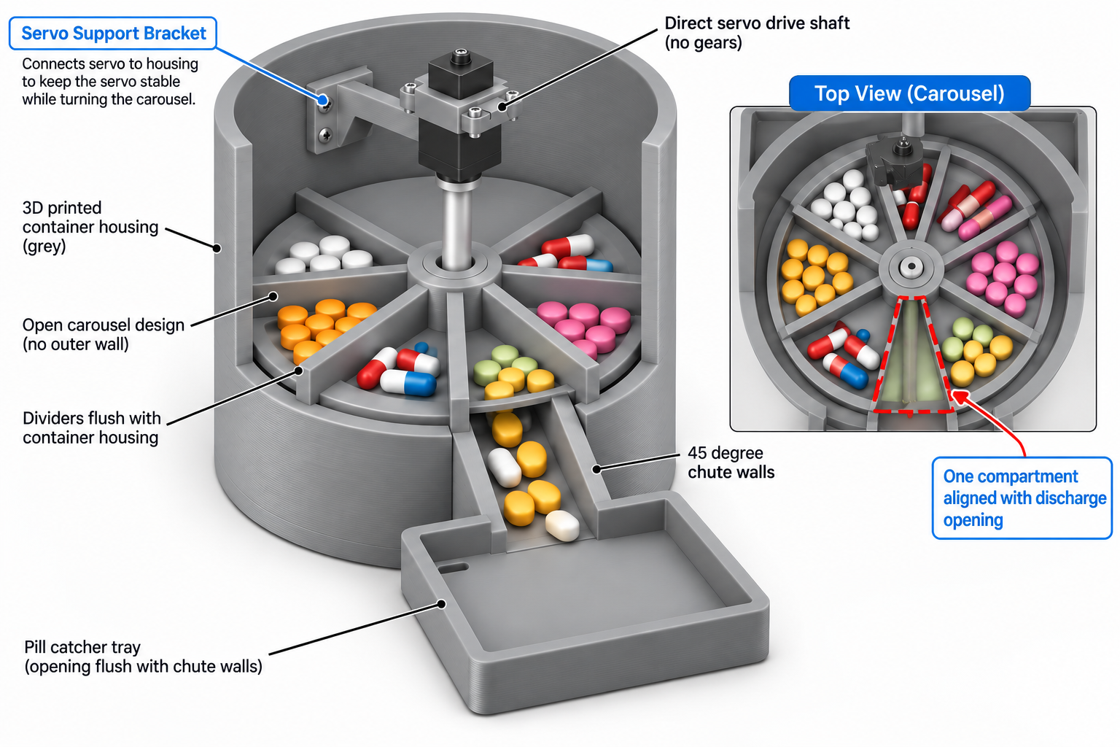
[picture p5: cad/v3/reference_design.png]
v3 reference design


---

## 1. Design intent read from the reference

| Feature in the drawing | How it is built |
| :--- | :--- |
| Grey cylindrical container housing | 120 mm OD drum, 3 mm wall, 106 mm tall |
| Open carousel, **no outer wall** | Compartments are closed on the outside by the drum bore; the carousel is a hub + 8 radial dividers, nothing else |
| Dividers flush with the housing | 0.35 mm running gap to the deck below, 0.7 mm sweep gap to the bore |
| 8 compartments | 45 deg pitch, ~4.6 cm3 each |
| Direct servo drive shaft, no gears | MG90S above the carousel, printed shaft extension down to the hub |
| Servo support bracket | L bracket cantilevered from the inner wall to the axis, gusseted and ribbed |
| Discharge opening | One 24 deg wedge through the deck, feeding straight into the chute |
| 45 deg chute walls | Chute is integral to the housing: the channel ramps down and out through the wall |
| Pill catcher tray, opening flush with the chute walls | Mouth wall cut down; the chute lip overhangs into the well |

Load-bearing consequence of "no outer wall": the drum bore is a sealing surface,
so it must stay round and the carousel must never be forced against it. Every
clearance in section 5 follows from that.

---

## 2. Why the mechanism works, and the one number that makes it work

The deck holds the pills in. It has one wedge opening. The unit rests with the
**just-emptied compartment centred on that opening**, so there is nothing above
the opening to fall through. A 45 deg step sweeps the next compartment across the
opening and gravity empties it into the chute. One servo, no gate, no carousel
floor — the compartments are open bins exactly as drawn.

That only holds if the opening fits inside one compartment's interior with room
to spare, measured at the opening's inner radius, where a divider subtends the
most angle:

```
open_deg  <=  360/car_n - 2*asin(div_t / (2*open_r_in)) - 2*park_margin
24        <=  45        - 8.6                          - 12.4
```

So the design runs a **+/- 6.2 deg parking margin**: park more than that off
centre and the opening's edge slips past the divider and starts draining the next
compartment. `parameters_v3.scad` derives `park_margin` and every part echoes it,
so widening the opening or moving it inward fails loudly rather than silently.

Consequences worth knowing before you print:

- A **positional** servo is required. A continuous-rotation servo stepped on
  timing alone will drift past 6 deg within a few doses. A standard 180 deg MG90S
  parks to about 1 deg, well inside budget, and gives 45 deg steps across four
  stops per sweep.
- If you later want all 8 bins per fill from a continuous-rotation servo, the
  cheapest fix is one lever microswitch tripped once per revolution to re-zero,
  not a wider opening.

---

## 3. Why the housing is two prints

The deck — the surface the pills sit on and the dividers sweep — is a 114 mm disc
52 mm up inside a drum. As one piece that is either an unprintable bridge or a
support forest against the one surface that has to stay flat.

Split at the deck plane, both halves are trivial:

- **Deck body (A3)** prints as modelled: the deck's flat underside is the first
  layer, the wall rises from it, the wedge is just a hole, the pilot post grows
  upward. No supports.
- **Base body (B3)** prints open-end-down: the chute floor and the external run
  are 40-42 deg overhangs, self-supporting. No supports.

Three screwed ears outside the drum join them. Concentricity between the bodies
is deliberately not critical: the running surface *and* the bore are both on the
deck body, so only the chute has to line up, and +/- 1 mm there is harmless.

With the deck integral to the drum, the v1 failure where the drop plate rotated
instead of the carousel is designed out rather than fastened out.

---

## 4. STL manifest

Seven functional parts, three test coupons.

| # | Source file | STL | Qty | Function | Print orientation | Supports |
| ---: | :--- | :--- | ---: | :--- | :--- | :--- |
| 1 | `part_a3_deck_body.scad` | `part_a3_deck_body.stl` | 1 | Drum wall + integral deck + 24 deg wedge + pilot post + bracket screw seats + joint ears | Deck underside down | none |
| 2 | `part_b3_base_body.scad` | `part_b3_base_body.stl` | 1 | Bay + 45 deg chute + wall notch + shoulder fins + cover posts + cable port | Open end down, as modelled | none |
| 3 | `part_c3_carousel.scad` | `part_c3_carousel.stl` | 1 | Hub + 8 dividers, no floor, hex socket + pilot journal | Divider ends and hub flat on the bed | none |
| 4 | `part_d3_drive_shaft.scad` | `part_d3_drive_shaft.stl` | 1 | Horn pocket, column, hex foot | Head down | brim |
| 5 | `part_e3_servo_bracket.scad` | `part_e3_servo_bracket.stl` | 1 | Wall pad + gusset + ribbed arm + MG90S plate | Flipped, flange plane down: the pad's, arm's and servo plate's top faces are coplanar, so they form one flat footprint | none |
| 6 | `part_f3_catch_tray.scad` | `part_f3_catch_tray.stl` | 1 | Tray, mouth wall cut down to the chute lip | Flat | none |
| 7 | `part_g3_base_cover.scad` | `part_g3_base_cover.stl` | 1 | Electronics floor, foot pads | Flat | none |
| C1 | `coupon_1_sector.scad` | `coupon_1_sector.stl` | 1 | 74 deg deck sector with the wedge and pilot post + 104 deg carousel sector with the whole hub: proves the running and sweep gaps | laid out, both flat | none |
| C2 | `coupon_2_drive_train.scad` | `coupon_2_drive_train.stl` | 1 | Bracket's servo plate + the real D3 shaft + the hub's socket end: proves the three drive-train fits | laid out, shaft head down | brim under the shaft |
| C3 | `coupon_3_chute_dock.scad` | `coupon_3_chute_dock.stl` | 1 | Chute exit with the lip + the tray's mouth wall: proves the dock and the ramp in plastic | laid out, both as modelled | none |

Every part module works in assembly coordinates so the preview can use it as-is;
each file's top-level call applies that part's print orientation, which is what
`--stl` exports. So the STLs load onto the bed ready to slice — do not re-orient
them — while the preview still shows the parts where they actually sit.

Shared: `parameters_v3.scad`, `lib_v3.scad`, `assembly_preview_v3.scad`,
`check_drop_path.scad` (section 11), `check_carousel_clearance.scad` (section 12),
`render_all_v3.sh` (previews by default,
`--stl` to export).

---

## 5. Locked parameters

Drum and deck:

| Parameter | Value | Why |
| :--- | :--- | :--- |
| Drum OD / wall / bore | 120 / 3.0 / 114 mm | fits any 180 mm bed; 3 mm is 7 perimeters at 0.4 mm |
| Rim height | 106 mm | set by the bracket screws, not by looks: both have to land in wall that is above the carousel sweep (section 12) |
| Deck thickness | 5 mm | it is structural now, not a drop-in plate |
| Deck top | z = 57 mm | leaves a 52 mm bay for the chute and electronics |
| Wall/deck fillet | 1.2 mm | dividers are chamfered 1.6 mm to clear it |
| Pilot post | 10.0 mm dia, 3.1 mm tall | the carousel's only bearing |
| Joint | 3 ears at 30/150/270 deg, 3x M3 | outside the drum, nothing in the pill path |

Carousel:

| Parameter | Value |
| :--- | :--- |
| Compartments | 8 at 45 deg pitch |
| Carousel OD | 112.6 mm, i.e. 0.7 mm sweep gap per side |
| Divider thickness / height | 2.4 / 26 mm |
| Running gap to deck | 0.35 mm |
| Hub | 28 mm OD, 12 mm A/F hex socket +0.3 mm slip (6.9 mm of hub wall left) |
| Capacity | ~4.6 cm3 per bin, roughly 10-14 standard tablets |

Discharge and chute:

| Parameter | Value |
| :--- | :--- |
| Deck opening | 24 deg sector, r 16 to 57 (breaches the bore) |
| Park margin | +/- 6.2 deg, derived not asserted |
| Lead-in relief | 1.2 mm on the opening's top face |
| Chute inside width | 14 mm at the deck, 32 mm from mid-ramp out |
| Ramp | One continuous surface, y = 14 to 70. Starts *inside* the opening's 16 mm inner radius, so every tablet lands on ramp, never on its leading edge |
| Ramp slope | 38-42 deg on top; floor thickens 2.4 to 6.5 mm so the *underside* stays 40-42 deg |
| Wall notch | 32.8 mm wide, z 4 to 52. Cut as a box **minus the chute solid**, so the ramp and the chute's walls cannot be breached; only housing wall is removed |
| Notch hoop strip | Wall kept below z = 4 — closes the first layers into a full ring and stiffens the two wall ends |
| Chute lip | z = 8 mm at y = 70, overhanging the tray by 2 mm; tray mouth wall 3 mm, so 1.5 mm of clearance under the lip |

Drive train:

| Parameter | Value |
| :--- | :--- |
| Bracket reach | 57 mm; arm 22 x 8 mm plus 12 mm ribs; 18 mm gusset web |
| Bracket pad | z 85 to 112, 26 x 6 mm. Starts 1.65 mm above the divider tops; anything reaching below z 83.35 jams the carousel solid |
| Wall screws | 2x M3 from outside into the pad at z 90 and 101 — clear of the sweep, still inside the wall |
| Servo plate | 4.5 mm thick — thinner than the servo's 6 mm nose, or the shaft head fouls it |
| Flange plane | z = 112 mm |
| Shaft | 30.15 mm overall: 26 mm head, 10 mm column, 12 mm A/F hex foot with a 45 deg ramp up to the column |
| Coupling play | +/- 2.58 deg, derived and asserted against the park margin (section 13) |
| Step per dose | 45 deg |

---

## 6. Print plan

| Part | Est. filament | Est. time |
| :--- | ---: | ---: |
| C1-C3 coupons | ~30 g | ~1.5 h |
| A3 deck body | ~98 g | ~8 h |
| B3 base body | ~85 g | ~7 h |
| C3 carousel | ~35 g | ~3 h |
| F3 tray | ~25 g | ~2.5 h |
| G3 base cover | ~25 g | ~1.5 h |
| E3 bracket + D3 shaft | ~23 g | ~2 h |
| **Total** | **~320 g** | **~25.5 h** |

PLA, 0.4 mm nozzle, 0.2 mm layers, 3 perimeters, 20-25 % infill, no supports on
any part. Iron the deck body's top face if your slicer can — that is the running
surface. The chute's underside is a 40-42 deg overhang: it prints unsupported but
will look slightly rough, and it is a cosmetic surface.

---

## 7. Bought parts

| Qty | Item | Note |
| ---: | :--- | :--- |
| 1 | MG90S, **positional** (not continuous rotation) | see section 2 |
| 1 | Round servo horn, 4-hole | 20.4 mm disc |
| 2 | M3 x 10 self-tapping | bracket, from outside the wall |
| 3 | M3 x 10 self-tapping | body joint ears |
| 3 | M3 x 10 self-tapping | base cover into the posts |
| 2 | M2 x 6 | servo flange |
| 4 | M2 x 6 self-tapping | horn into the shaft head |

No bearings, no rods, no gears, no second servo.

---

## 8. Print the coupons first

About 90 minutes of printing that de-risks 23 hours. Each coupon is cut from the
real parts, so it carries the real dimensions rather than a copy of them, and each
one isolates the fits that a render cannot prove. Full instructions are in the
header of each file.

1. **C1 sector** (`coupon_1_sector.scad`) — drop the carousel sector onto the deck
   sector and spin it. Looking for no rub on the deck, no rub on the bore, no
   rocking, and a tablet that sweeps rather than slipping under a divider. If it
   rubs on the deck, `car_gap` changes; if it rubs on the bore, the 1.4 mm in
   `car_od` changes. Nothing else does.
2. **C2 drive train** (`coupon_2_drive_train.scad`) — the MG90S must drop into the
   bracket pocket without forcing, the horn must seat flush in the shaft head, and
   the hex must drop into the hub under its own weight and then rock less than a
   couple of degrees — that rotational play lands straight on the park angle, so
   this is the coupon that protects the +/- 6.2 deg margin (section 13). If it
   needs forcing, `hex_slip` goes up; if it rattles, it goes down. Stacking all
   three also measures the shaft head's 1.5 mm clearance under the servo plate,
   which is the one clearance a render can flatter.
3. **C3 chute dock** (`coupon_3_chute_dock.scad`) — the lip must overhang into the
   tray with clearance over the mouth wall, and a tablet rolled down the ramp must
   land on the tray floor without stopping on the lip or catching on the wall.
   Sight along the ramp against the light: this is where you confirm in plastic
   what section 11 proves in CAD.

Only then print A3 and B3.

---

## 9. Where this stands

| Gate | Step | State |
| :--- | :--- | :--- |
| G1 | `parameters_v3.scad`, `lib_v3.scad` | done — echoes the derived park margin |
| G2 | A3 deck body, B3 base body | done — render clean, chute fused into the wall |
| G3 | C3 carousel, D3 shaft, E3 bracket | done — shaft clears the servo plate by 1.5 mm |
| G4 | F3 tray, G3 base cover | done |
| G5 | Previews: 7 parts + 2 details + 5 assembly views + annotated hero | done, in `previews/` |
| G6 | Ramp continuity | done — `check_drop_path.scad`, see section 11 |
| G7 | `render_all_v3.sh --stl` | done — 7 STLs in `stl/`, each watertight, each in its print orientation |
| G8 | Coupons C1-C3 | done — cut from the real parts, exported to `stl/` |
| G9 | Firmware constants | done — see section 10 |

---

## 10. Firmware touch points

`firmware/pill_dispenser/pill_dispenser.ino` is on the v3 mechanism:

- 45 deg per dose, absolute stops rather than timed steps
- park position = the opening's centre, so the emptied bin covers the wedge
- 600 ms dwell after each step for the dose to reach the tray, before the vision
  check reads it
- the v1 latch servo is gone; D10 is free
- `car_n`, `car_pitch`, `park_margin` and `hex_backlash` are **generated** out of
  `parameters_v3.scad` into `pill_dispenser/v3_geometry.h` by
  `firmware/tools/geometry_from_cad.sh`, so the two cannot drift
- moves are ramped at 180 deg/s and commanded as pulse widths, because `write()`
  quantises to 1 deg and this margin cannot afford it
- the shaft is commanded past the stop by `hex_backlash` in the direction of
  travel, so the *carousel* lands on the stop; a reverse sweep flips the sign

The consequence worth planning around is the park error budget, not the torque
(section 13). Assembly can only index the carousel in 17.1 deg horn teeth, 60 deg
hex seatings and 90 deg horn screws, so up to 8.6 deg of park offset has to be
trimmed in firmware. That authority plus the coupling's play must be reserved at
both ends of the servo's travel, which is what sets the doses per fill:

    DOSES_PER_FILL = (TRAVEL_DEG - 2 * (TRIM_RANGE_DEG + hex_backlash)) / 45

A nominal 180 deg servo gives **three** doses; a measured 203 deg or more gives
four. The sketch derives it, reports it in its boot banner, and refuses the dose
after the last stop with `ERR_MAGAZINE_EMPTY` rather than pushing into the end of
the travel. `REZERO` sweeps back to stop 0 — safe only because the compartments it
crosses are the ones just emptied. All 8 bins per fill still needs a
continuous-rotation servo plus a lever microswitch to re-zero, which is the upgrade
named in section 2.

`firmware/test/run.sh` proves all of that on the host, with no board.

---

## 11. Checking the ramp is continuous

A tablet leaves the carousel through the deck's wedge and is then on its own until
it reaches the tray. Anywhere the ramp is interrupted, it drops into the
electronics bay instead — a silent partial dose, which is the worst failure this
machine has. Two things guarantee it cannot happen, and one check proves it.

The ramp starts at y = 14, inside the opening's 16 mm inner radius, so it extends
under the whole wedge rather than starting at its edge. And the notch through the
drum wall is cut as a box **minus the chute solid**, so the subtraction can only
ever remove housing wall — retuning `chute_stations`, `chute_win_w` or the notch
heights cannot put a hole in the floor.

`previews/v3_chute.png` is the section that shows it, and
`previews/v3_drop_path.png` shows the fall volume sitting on the ramp.

`check_drop_path.scad` proves it rather than assuming it. It intersects the base
body with the exact volume a tablet can fall through (the wedge, extruded from the
deck's underside down to the bay floor) and shows what material is inside it. Open
it, F5, then look straight down: the wedge footprint must be filled edge to edge.
Since the notch removes everything else under the wedge, anything you see there is
ramp, and any daylight is a hole. Re-run it after touching the chute.

---

## 12. Checking the carousel can turn

The dividers are radial, so as the carousel turns it does not sweep a thin shell —
it sweeps one solid ring: everything from z 57.35 to 83.35, from the hub out to
r 56.3. Any fixed material inside that ring is not a tight fit, it is a dead stop
on the first step, and a render hides it well: the bracket reads as *behind* the
carousel when it is really *in* its path.

That is exactly what the first cut of E3 did. Its pad stood 6 mm off the bore from
z 72 up, putting a 26 x 10.6 x 11.35 mm block of bracket inside the ring, 26 mm of
arc wide — over half a compartment pitch. All eight dividers would have hit it.

Three things now keep it out, and the geometry drives all of them:

- `brk_pad_z0 = car_top + brk_clear` — the pad cannot start below the divider tops
  because it is *derived* from them, not typed in.
- `brk_web_h` is whatever fits between the arm and the pad's foot, less 1 mm, so
  the gusset's lower tip stays out too.
- `rim_z = 106` exists to give both wall screws somewhere to land above the sweep.
  Lower the rim and the upper screw runs out of wall; `parameters_v3.scad` asserts
  that and says so.

`check_carousel_clearance.scad` proves it on the real geometry rather than on the
parameters. It intersects each fixed assembly with the swept ring, which it builds
by revolving the divider's own profile — chamfer included, so the wall/deck fillet
does not read as a clash when the 1.6 mm chamfer already clears it:

| MODE | What | Must show |
| ---: | :--- | :--- |
| 0 | bracket in the ring | nothing at all |
| 1 | deck body in the ring | the pilot post only — that one is the bearing |
| 2 | base body in the ring | nothing at all |
| 3 | drive shaft in the ring | the hex foot only — it turns with the carousel |
| 4 | the swept ring alone | for orientation |

Re-run it after moving the bracket, the rim, the wall or the divider height.

---

## 13. Will the MG90S actually turn it?

Torque first, worst case, every bin full:

| Term | How it arises | Torque |
| :--- | :--- | ---: |
| Thrust friction | the carousel hangs on the pilot post's 10 mm top face, `(2/3)·mu·W·R` | 0.5 mN·m |
| Tablet friction | 40 g of tablets sliding on the deck at a 35 mm mean radius, tripled for ploughing and pinching against the bore | 16.5 mN·m |
| Inertia | 8.7e-5 kg·m2 taken through 45 deg in 150 ms with a 50 ms ramp | 13.7 mN·m |
| **Demand** | | **31 mN·m = 0.31 kg·cm** |

Assumptions, all deliberately pessimistic: carousel 45 g (its 36.45 cm3 taken as
solid PLA, though it prints lighter), 40 g of tablets (8 bins x 12 x 0.4 g),
mu 0.35 PLA on PLA and 0.40 tablet on PLA, and an acceleration the servo will not
actually manage.

An MG90S is 1.8 kg·cm at 4.8 V and 2.2 kg·cm at 6 V, so **5.8x** margin at 4.8 V.
Derate a cheap clone 30 % and run it off the bare 3.7 V cell, which is below its
rated range, and there is still 3x. Torque is not what limits this mechanism.

Nor is strength: at stall the 12 mm hex sees 0.16 MPa on its flats and the 10 mm
PLA column under 1 MPa in torsion. The servo's nylon horn spline is the weak
point, which is the right place for one.

What *does* limit it is the park angle, and the coupling is most of the error
budget. The hex is loose on purpose, and a forward step ends with the driving
flats in contact, so the carousel parks behind its stop by the full play. At the
original 7 mm A/F and 0.4 mm slip that was +/- 6.28 deg — the entire +/- 6.2 deg
park margin, spent before the servo has contributed anything. Play goes as slip
over size, so widening the hex to 12 mm and easing the slip to 0.3 mm brings it to
+/- 2.58 deg while keeping a fit you can still drop together by hand.
`parameters_v3.scad` derives that figure and asserts it stays 2 deg inside the
margin, which leaves the servo's own ~1 deg and the print's tolerance somewhere to
live. `REZERO` reverses, so after one the carousel rests on the other flank — same
magnitude, other sign, still inside.

Speed and supply are comfortable. An MG90S slews 60 deg in about 0.1 s at 4.8 V,
so a 45 deg step takes roughly 75 ms unloaded and 110-150 ms under this load,
against the firmware's 400 ms allowance and a 600 ms fall window after it. Feed
the servo 5 V — USB, or a 5 V bank — with a bulk capacitor across it rather than
the 3.7 V cell, and let the firmware detach it after every cycle so the idle draw
is nothing.

---

## 14. Risks

| Risk | Mitigation |
| :--- | :--- |
| Bracket twists under servo reaction torque | 18 mm gusset web, 12 mm ribs, two screws 11 mm apart in the pad; if it still flexes, move the leg outside the drum where it can be as deep as you like |
| Deck warps and the carousel binds | Deck prints as the first layer; the 0.35 mm gap absorbs the rest; coupon C1 proves it before the 7 h print |
| Servo parks outside +/- 6.2 deg | Use a positional servo; verify each stop by eye on the first fill |
| Tablets wedge at the wedge edge | 1.2 mm lead-in relief on the opening's top face |
| Chute cantilevers out of the notch | Notch is only as wide as the pill passage so the chute's own walls fuse into the wall, plus two shoulder fins back to the bore and a hoop strip under the notch |
| A tablet drops through a gap in the ramp | The notch cannot breach the floor by construction, and `check_drop_path.scad` proves it — section 11 |
| Carousel parks outside the window because of coupling play | 12 mm hex at 0.3 mm slip holds the play to +/- 2.58 deg, asserted against the derived park margin — section 13 |
| Something fixed ends up in the carousel's path | Pad and gusset are derived off `car_top`, `parameters_v3.scad` asserts it, and `check_carousel_clearance.scad` proves it on the geometry — section 12 |

---

## 15. Not in v3

- No gate or shutter. The park convention makes one unnecessary.
- No homing sensor. Only needed if you insist on a continuous-rotation servo.
- No lid. The drawing has none and the bracket occupies the rim.
- No pocket inserts. Add them if small tablets rattle in a 4.6 cm3 bin.

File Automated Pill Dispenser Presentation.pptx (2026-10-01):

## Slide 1

MEDTECH PROTOTYPE | APPLIED AI | DATA ENGINEERING

Automated Pill Dispenser

Dispense, verify, and measure every dose: a $100 to $150 station that closes the medication adherence loop

3D-printed carousel + edge computer vision + Databricks analytics
45-minute session, including a 15-minute live demo

github.com/arewa-builds/AutomatedPillDispenser

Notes: Slide 1. Title (0:00 to 1:00)
Good evening everyone. Thank you for being here.
Today I'm going to provide a demonstration of my most recent project, the Automated Pill Dispenser. It's a small station that does three things for every dose: it dispenses the pill, it uses a camera to confirm the patient is there and that the pill actually dropped, and it streams every event into Databricks. The station costs between 100 and 150 dollars to build.
The idea is simple. Medication adherence is usually a guess. This project turns it into data.
We'll spend about 20 minutes on the build, 15 minutes in a live demo of the Databricks tables and dashboard, and then we'll close with the financial case for healthcare.

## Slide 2

ABOUT ME

Arewa Ojelade: AI Robotics Engineer

Related builds

GitHub: github.com/arewa-builds

- Patient Readmissions: 30-day readmission risk model with Tableau
- PharmaVerse: synthetic pharma line clearance in Isaac Sim
- SurgicalVision: CPU-only surgical simulation coaching

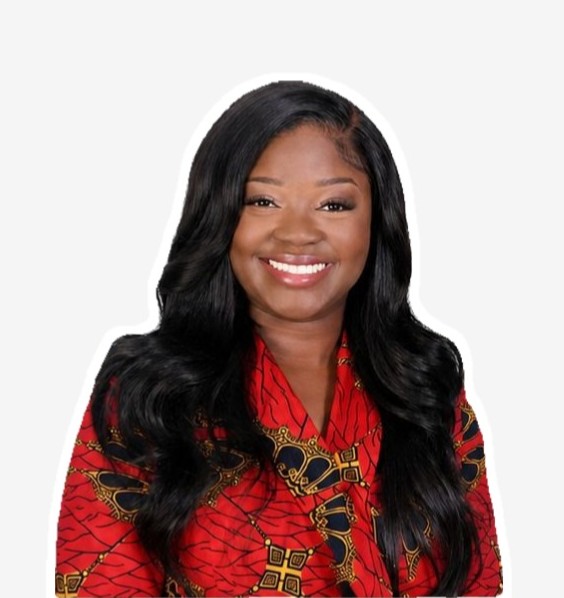
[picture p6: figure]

Background

AI and Robotics Engineer Pharmaceutical Manufacturing
monitoring, calibration automation, anomaly detection
University of Maryland Global Campus
B.S. Computer Science; MBA, Data Science concentration

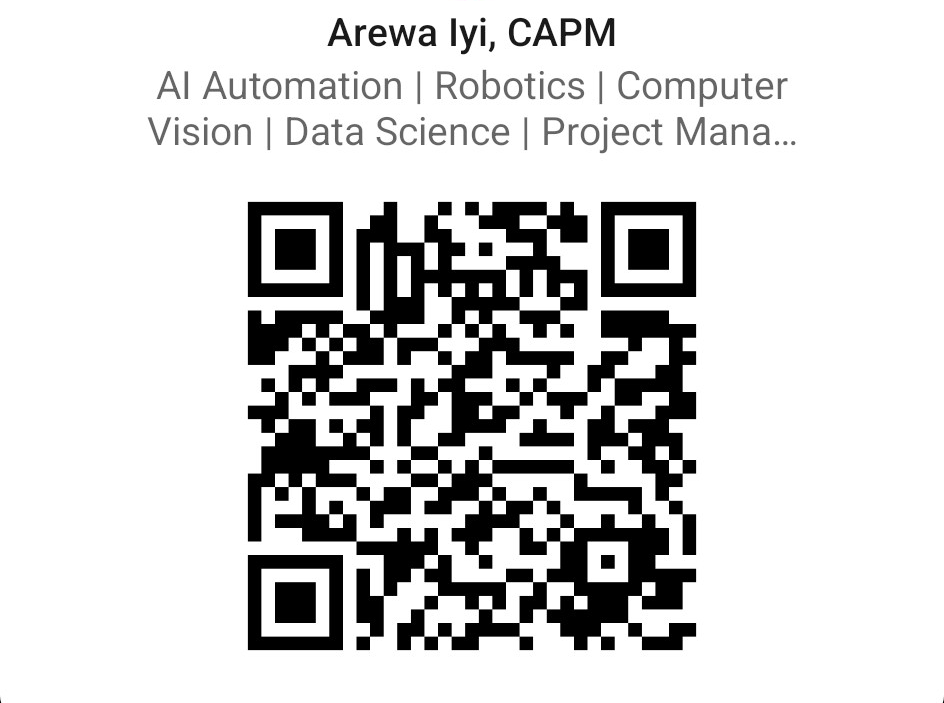
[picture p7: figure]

Toolkit

Python, FastAPI, LangChain, LangGraph, ONNX Runtime, OpenCV, MediaPipe, Databricks, Arduino, OpenSCAD

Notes: Slide 2. About me (1:00 to 2:00)

A little bit about me. My name is Arewa. I'm an AI Robotics Engineer in the Pharmaceutical Manufacturing sector, and I have evolved to working at the intersection of artificial intelligence, hardware and data , specializing in manufacturing monitoring, anomaly detection and omniverse simulation research.

I studied computer science for my bachelors and am currently finishing up my MBA with a data science concentration.

My most recent project showcased for South Florida Data Geeks is an Isolation Forest model that predicts 30-day hospital readmission risk visualized with Tableau. I have also recently been conducting research on building virtual omniverse pharmaceutical manufacturing environments to generated labled synthetic computer vision data to evaluate models and test physical AI before deploying in real production line.

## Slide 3

AGENDA

Where the next 45 minutes go

Why non-adherence is a clinical problem as much as a data one

0 to 7 min

Intro and problem

Four layers, one closed loop from servo to dashboard

7 to 11 min

System design

Mechanism, vision, data pipeline, and safety findings

11 to 20 min

Build highlights

Device mock run, Bronze to Gold tables, dashboard walkthrough

20 to 35 min

Live demo

Non-adherence cost, readmission penalties, savings, dementia care

35 to 43 min

Financial impact

What ships next and what still needs validation

43 to 45 min

Roadmap and Q&A

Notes: Slide 3. Agenda (2:00 to 3:00)

Here's where the next 45 minutes go.

We start with the problem, then the system design, then four build highlights for about 20 to 35 minutes, then we dive into the demo and explore our dashboard in Databricks. That's the centerpiece. After that, we discuss the financial impact, and we finish with the roadmap and your questions.

If the live connection misbehaves, I have a backup slide with every number already verified, so we won't lose anything.

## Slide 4

THE PROBLEM

Half of filled prescriptions are taken incorrectly, and the cost lands on hospitals

$100-300B

Direct US health care cost tied to non-adherence every year

~50%

Of filled prescriptions taken incorrectly: timing, dose, frequency, or duration

125,000

US deaths per year attributed to poor medication adherence

10%

Of US hospitalizations linked to non-adherence

Timing is the most common failure mode, and it is exactly what a connected dispenser can observe and timestamp.

Source: CDC MMWR 2017 (https://www.cdc.gov/mmwr/volumes/66/wr/mm6645a2.htm), NIH PMC review 2023 (https://pmc.ncbi.nlm.nih.gov/articles/PMC10372970/)

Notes: Slide 4. The problem (3:00 to 5:00)

Let’s talk about the problem this project aims to solve

According to the CDC, about half of filled prescriptions are taken incorrectly. Incorrectly can be defined as wrong timing, the wrong dose, the wrong frequency, or stopping too early.

Non-adherence costs the US health system between 100 and 300 billion dollars a year in direct costs. It's linked to about 125,000 deaths a year and to roughly 10 percent of hospitalizations.

[Pause.]

The point I want you to remember as engineers is this: the most common failure is timing, and timing is almost never recorded.
That missing data is the opportunity, and a connected dispenser can observe and timestamp it.

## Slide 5

THE GAP

Reminders tell patients when; nothing confirms that it happened

Typical pillbox or reminder app

- Alarm fires at dose time
- No proof the right person was there
- No proof a single pill came out
- Caregiver learns about a miss days later, if at all

This prototype

- Face gate: dispense only when a person is present
- Pill check: camera counts what landed in the tray
- Every dose logged with drift, latency, and confidence
- Trend analytics flag drift before a full miss

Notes: So what's out there today?

On the left is the typical pillbox or reminder app. An alarm goes off. But there's no proof the right person was there, no proof that exactly one pill came out, and the caregivers usually finds out about a missed dose days later, if at all.

On the right is what this prototype does. First, a face gate: it only dispenses when a person is actually present. Second, a pill check: the camera counts what landed in the tray. Third, every dose is logged with timing drift, latency, and detection confidence. And fourth, the analytics look for drift before it turns into a full missed dose.

That last point matters. People rarely go from perfect to missing doses overnight. They drift later and later first. Drift is an early warning signal.
The design goal is non-invasive caregiving: no wearables, and no app the patient has to open. The device acts, observes, and reports.

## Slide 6

SYSTEM DESIGN

Assisted Design - Four Layers
software-first so every layer can be tested without hardware

Layer | Stack | Responsibility
Embedded | Arduino Nano 33 BLE, positional MG90S servo, LiPo + TP4056 + boost | Carousel indexing and dispensing
Edge vision | Python, OpenCV, MediaPipe BlazeFace, PySerial | Face gate, pill count, serial DISPENSE handshake
Data | Databricks Delta tables via SQL Statement Execution API | Bronze, Silver, Gold medallion transforms
Analytics | Databricks AI/BI dashboard on a serverless SQL warehouse | Adherence, drift, status, and dashboard analysis

Hardware budget: $100 to $150 all-in with cloud trial. Mock mode runs everything on a laptop.

Source: AutomatedPillDispenser repo (https://github.com/arewa-builds/AutomatedPillDispenser)

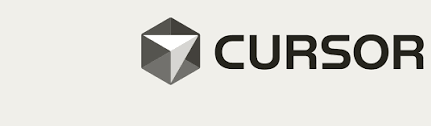
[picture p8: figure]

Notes: Slide 6. System design (7:00 to 9:00)

The system has four layers.

The embedded layer is an Arduino Nano 33 BLE driving a single positional MG90S servo. It moves the carousel 45 degrees per dose, with absolute stops.
The edge vision layer is Python with OpenCV and MediaPipe, and PySerial

These four run the edge program on the laptop. A dose proceeds only after a face stays in view, the Nano moves the carousel, and the tray shows one new pill.

Python is the program that runs that cycle. It opens the camera, decides when to dispense, writes the JSONL event, and inserts the same row into Bronze when the Databricks token is set.

MediaPipe BlazeFace decides whether a person is in front of the camera. It checks presence, not identity. The carousel does not move until the face stays above the confidence threshold for several frames.

PySerial is the USB link to the Nano on COM3. After the face is stable, Python sends DISPENSE and reads the acknowledgement. That command is what turns the servo.

OpenCV runs the camera and checks the tray. It grabs the laptop camera at index 0, counts pill-colored blobs before and after the move, and draws the preview window. A successful cycle is a count that goes up by one.

The data layer is Databricks Delta tables, written through the SQL Statement Execution API.

The analytics layer is a Databricks dashboard running on a serverless SQL warehouse.

The hardware costs around 100 -150 all-in with the cloud trial.

One design choice I want to highlight: I built this software-first. Every layer runs without the others. The firmware has a host test harness. The edge pipeline has a mock Arduino. And the data transforms run locally on synthetic data before they ever touch Databricks. That's how I could build and test the whole pipeline before the hardware was ready.

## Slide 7

ONE DOSE, END TO END

Every dispense becomes a row in Databricks within seconds

Face gate

8 stable frames at ≥0.65 confidence

1

DISPENSE

release command, ACK, retry limit 2

2

Carousel

Servo advances one 45° bin

3

Pill check

Count delta in tray, 3 s timeout

4

Log

Local JSONL + Bronze insert

5

Analyze

Silver, Gold, dashboard

6

Bronze row: event_ts, patient_id, face_match_confidence, pills_detected,
dispense_latency_ms, event_status, hardware_source, retry_count

Source: AutomatedPillDispenser repo (https://github.com/arewa-builds/AutomatedPillDispenser)

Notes: Slide 7. One dose, end to end (9:00 to 11:00)
Let's follow one dose through the system.

Step one, the face gate. MediaPipe needs eight stable frames at 0.65 confidence or higher before it allows a dispense. That stops a passing shadow from triggering anything.

Step two, the dispense command enables release. The device acknowledges it, and there's a retry limit of two.

Step three, the servo advances the carousel by one 45-degree bin.

Step four, the pill check. The camera counts pills in the tray against a baseline, with a three-second timeout. We count the change, not the total, because pills stay in the tray. The second dose is a count of two, not another one.

Step five, the event is written to a local JSON Lines file and inserted into the Bronze table in Databricks. If the network is down, the dose is still recorded locally.

Step six, Databricks turns it into Silver and Gold tables and the dashboard.

At the bottom of the slide, you can see the eight fields in every Bronze row. Remember these, because you'll see them live in a few minutes.

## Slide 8

HIGHLIGHT 1: MECHANISM

The v3 design is built around one number: ±6.2° of parking margin

Seven printable parts plus three test coupons; firmware geometry is generated from the CAD so the two cannot drift.

Source: cad/v3 README (https://github.com/arewa-builds/AutomatedPillDispenser/tree/main/cad/v3), firmware README (https://github.com/arewa-builds/AutomatedPillDispenser/tree/main/firmware)

8 bins, 45° steps

Integral deck, open compartments, one positional servo

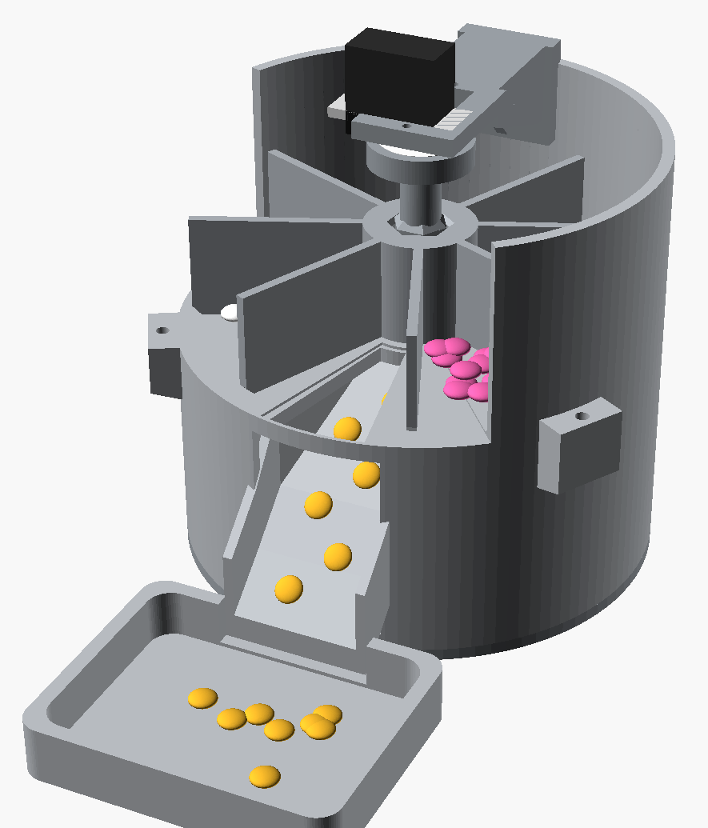
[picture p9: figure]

24° wedge

Single opening over the chute; the emptied bin parks on it

±2.58° play

12 mm hex coupling instead of 7 mm (which would be ±6.28°)

~6x torque

MG90S headroom, so the error budget drives the design

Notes: Slide 8. Highlight 1: the mechanism (11:00 to 13:30)

The first highlight is the mechanism. The whole v3 design comes down to one number: plus or minus 6.2 degrees of parking margin.
Here's why. The carousel has eight open bins in 45-degree steps. There's a single 24-degree opening in the deck above the chute. When the carousel is at rest, the bin that was just emptied sits over that opening, so nothing can fall through. Each compartment spans about 36 degrees at that radius, which leaves 6.2 degrees of margin either side. If it parks further off than that, the opening starts draining the next bin. That's why v3 uses a positional servo instead of a continuous-rotation one.

The torque isn't the problem. The MG90S has roughly six times the torque this needs. The problem is the error budget. So I used a 12-millimeter hex coupling instead of 7 millimeters, which cuts the rotational play from about 6.3 degrees down to 2.58.
Assembly tolerances alone can still put the carousel up to 8.6 degrees off center, which is more than the margin. So the firmware has trim and jog commands that shift the stop positions at run time.

My favorite detail: the firmware's geometry constants are generated directly from the CAD parameters file. The mechanical design and the code can't drift apart.

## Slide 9

HIGHLIGHT 2: EDGE VISION AND FIRMWARE

Vision decides when to dispense and whether it worked

Face gate

- MediaPipe Tasks FaceDetector with a vendored BlazeFace short-range model
- Reduced-resolution input and a settling phase for fast startup
- DirectShow fallback for laptops whose camera will not open

Pill verification

- OpenCV HSV threshold plus contour area filter (80 to 8,000 px)
- Counts new pills against a baseline, so stacked doses are caught
- Status recorded as success, retry, or failure

Firmware

- Non-blocking state machine on one MG90S (pin D9)
- REZERO when the magazine is spent, before the turn check
- Host test harness runs the sketch logic without hardware

Source: PR #5 (https://github.com/arewa-builds/AutomatedPillDispenser/pull/5), PR #9 (https://github.com/arewa-builds/AutomatedPillDispenser/pull/9), PR #14 (https://github.com/arewa-builds/AutomatedPillDispenser/pull/14), PR #15 (https://github.com/arewa-builds/AutomatedPillDispenser/pull/15)

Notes: Slide 9. Highlight 2: edge vision and firmware (13:30 to 16:00)

The second highlight is the vision and firmware layer. Vision decides when to dispense and whether it worked.

For the face gate, I use the MediaPipe Tasks face detector with the BlazeFace short-range model bundled into the repo. It starts up on reduced-resolution frames with a short settling phase, so it's fast.

There's also a DirectShow fallback for Windows laptops where the camera won't open the normal way.
For pill verification, I use an OpenCV color threshold and contour filter, keeping shapes between 80 and 8,000 pixels in area. It counts new pills against the baseline, so if two pills drop at once, it notices. Every event is recorded as success, retry, or failure.

The firmware is a non-blocking state machine on one servo. When the magazine is empty, it re-zeroes before checking the next turn, which prevents the mechanism from burning through cycles.

To be clear about scope: today the camera confirms that a person is present. It doesn't identify who they are. Patient matching is on the roadmap.

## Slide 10

HIGHLIGHT 3: DATA PIPELINE

A medallion pipeline turns raw dispense events into an adherence signal

Bronze

bronze_dispense_events

Raw rows inserted per dose by the edge sink

Silver

silver_dispense_events

Adds is_success, scheduled_window, and time_drift_minutes from the 08:00 or 20:00 anchor

Gold

gold_adherence_7d

Adherence rate and risk flag: drift ≥ 15 min or adherence < 85%

Serving

dashboard_daily / weekly / monthly

Calendar spine keeps missed days visible as zero-event rows

Source: PR #20 (https://github.com/arewa-builds/AutomatedPillDispenser/pull/20), bronze_dispense_month.sql (https://github.com/arewa-builds/AutomatedPillDispenser/blob/main/databricks/sql/bronze_dispense_month.sql)

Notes: Slide 10. Highlight 3: the data pipeline (16:00 to 18:00)

The third highlight is the data pipeline, a standard medallion architecture.
Bronze holds the raw rows, inserted once per dose by the edge device. The same schema works for mock runs, synthetic data, and live hardware.
Silver adds three things: whether the dose succeeded, which dose window it belongs to, morning or evening, and the time drift in minutes from the 8 AM or 8 PM schedule.

Gold calculates the adherence rate and a risk flag. The rule is deliberately simple: flag the patient if average drift is 15 minutes or more, or if adherence drops below 85 percent.

The serving tables use a calendar spine, so a day with no doses still shows up as a zero instead of disappearing from the chart.

For the demo, I loaded a 90-day synthetic history from July 1 to September 29: 182 scheduled doses, 172 taken, and 10 missed on August 10 to 14. The missed doses count against adherence in Gold. Later, a machine learning model in MLflow will replace the simple risk rule.

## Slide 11

HIGHLIGHT 4: SAFETY FINDINGS

Live bench data caught a multi-pill dispense the moment it happened

What the telemetry showed

- 5 live bench dispenses on 29 Sep (7:43 to 8:16 PM ET)
- One event detected 3 pills; one detected 0 and logged as failure
- Four cycles ran within 23 seconds
- Result: 178 pills detected across 177 events

Safeguards added in response

- Exactly one actuation per dispense cycle
- Count-delta verification for the second dose
- Wait for the face to leave before the next cycle
- REZERO handling to stop magazine burn

Source: Databricks dashboard (https://dbc-841e48ce-abec.cloud.databricks.com/dashboardsv3/01f1bc66f608184bb87e728ccb7f308e/published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), AutomatedPillDispenser repo (https://github.com/arewa-builds/AutomatedPillDispenser)

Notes: Slide 11. Highlight 4: safety findings (18:00 to 20:00)

The fourth highlight is my favorite, because it's real.

On the evening of September 29, I ran five live dispenses from the actual hardware on my bench, and they went straight into Databricks. I've left them in the dashboard on purpose.

Look at what the telemetry caught. One event detected three pills. One detected zero and was logged as a failure. Four cycles ran within 23 seconds. Across the whole dataset, that's 178 pills detected over 177 events.

That's a multi-pill dispense, which is exactly the kind of safety issue that matters in a medication device. The data caught it the moment it happened.
In response, I added the safeguards on the right: exactly one actuation per dispense cycle, count-change verification for the second dose, waiting for the face to leave before the next cycle, and re-zero handling so the magazine doesn't burn through.

So let's look at this data live.

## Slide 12

LIVE DEMO | 15 MINUTES

Demo run of show: from a mock dispense to the adherence dashboard

python pipeline.py --mode mock: face gate, DISPENSE, pill count

20:00

2 min

Mock dispense

New row lands in bronze_dispense_events via the SQL API

22:00

3 min

Bronze

Drift from the dose anchor; misses counted in adherence

25:00

3 min

Silver and Gold

90-day trend, the 10 to 14 Aug gap, events by status

28:00

4 min

Dashboard

99.44% dispense success vs 94.12% scheduled adherence

32:00

1 min

Two rates

Why it is on, and what the test events do to drift

Source: Databricks dashboard (https://dbc-841e48ce-abec.cloud.databricks.com/dashboardsv3/01f1bc66f608184bb87e728ccb7f308e/published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), AutomatedPillDispenser repo (https://github.com/arewa-builds/AutomatedPillDispenser)

33:00

2 min

Risk flag

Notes: [20:00 to 35:00 | 15 min DEMO]
Pre-flight: set CAMERA_INDEX in edge/config.py to the camera you will use (currently 1); have edge/.env loaded with Databricks credentials; open the SQL editor and the published dashboard in separate tabs.
20:00 Mock dispense (2 min): run python pipeline.py --mode mock from edge/. Point out the face gate status, the DISPENSE handshake, and the pill count overlay.
22:00 Bronze (3 min): SELECT * FROM workspace.pill_dispenser.bronze_dispense_events ORDER BY event_ts DESC LIMIT 5. Show the new row. Explain the local JSONL fallback.
25:00 Silver and Gold (3 min): show silver_dispense_events columns is_success, scheduled_window, time_drift_minutes. Then SELECT * FROM gold_adherence_7d: 187 events, 176 successes, 11 missed, 94.12% adherence, 33.77 min drift, high_adherence_risk = true.
28:00 Dashboard (4 min): Weekly Events Trend plots pills detected per week; note the dip to 4 in the week of 10 Aug (10 missed doses) and the week of 28 Sep showing 10 pills across 9 events. Monthly: July 62, August 52, September 63. Events by status: 167 success, 9 retry, 1 failure.
32:00 Two rates (1 min): dashboard success rate is 176 of 177 = 99.44%, a dispense reliability metric. Scheduled adherence for the synthetic patient is 172 of 182 = 94.51%. Explain why both matter.
33:00 Risk flag (2 min): synthetic doses average 5.94 min of drift; the 5 live test rows are scored against the wrong anchor (223 and 1,183 min), lifting the average to 33.77 and triggering the flag. Turn this into a lesson: data quality and anchor logic matter as much as the model.
If anything fails live, switch to slide 13.

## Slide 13

DEMO BACKUP

Verified in Databricks: the dashboard reconciles to the tables row for row

Metric | Dashboard | Synthetic only
Events | 177 | 172
Dispense success | 99.44% | 100%
Pills detected | 178 | 172
Avg time drift | 33.77 min | 5.94 min
Avg latency | 1,246 ms | 1,227 ms
Adherence (Gold) | 94.12% | 94.51%

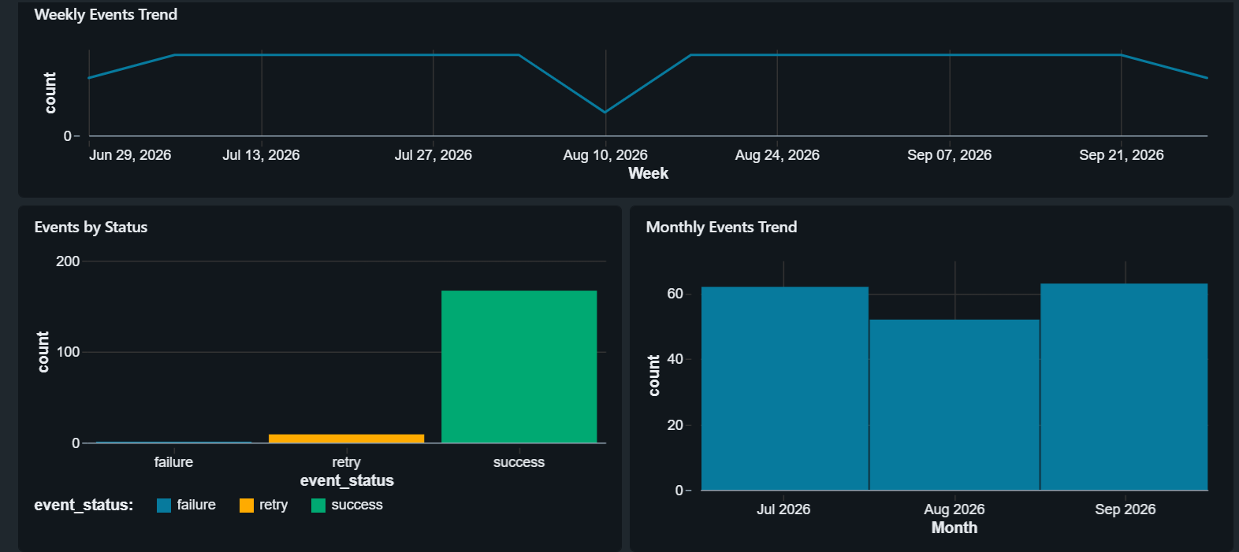
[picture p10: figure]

Synthetic patient: 182 scheduled doses, 1 Jul to 29 Sep 2026, 10 missed (10 to 14 Aug). Plus 5 live bench events on 29 Sep ET.

Source: Databricks dashboard (https://dbc-841e48ce-abec.cloud.databricks.com/dashboardsv3/01f1bc66f608184bb87e728ccb7f308e/published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), PR #20 (https://github.com/arewa-builds/AutomatedPillDispenser/pull/20)

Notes: Slide 13. Demo backup (only if needed)
[Use only if the live demo fails.]
Here are the same numbers, verified directly against the Databricks tables. The dashboard shows 177 events, 99.44 percent dispense success, 178 pills detected, 33.77 minutes of average drift, 1,246 milliseconds average latency, and 94.12 percent adherence in Gold.
If you take out the five live bench events, the synthetic patient is 172 events, 100 percent dispense success, 5.94 minutes of drift, and 94.51 percent scheduled adherence. The difference between those two columns is the data-quality story I just told.

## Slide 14

FINANCIAL IMPACT 1 OF 4

Non-adherence is a $100B to $300B line item that nobody measures at the point of use

$100B to $300B

Avoidable direct US health care spending linked to non-adherence each year

Most of that cost shows up as avoidable hospital admissions, not as pharmacy spend.

3.8 billion

Prescriptions written in the US each year

1 in 5

New prescriptions never filled

$409 billion

2026 US cost of care for people 65+ with dementia

Source: CDC MMWR 2017 (https://www.cdc.gov/mmwr/volumes/66/wr/mm6645a2.htm), Adherence and health care costs, PMC (https://pmc.ncbi.nlm.nih.gov/articles/PMC3934668/), 2026 Alzheimer's Facts and Figures (https://pmc.ncbi.nlm.nih.gov/articles/PMC13098189/)

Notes: Slide 14. Financial impact 1 of 4: the national cost (35:00 to 37:00)

Let's talk about Financial Impact

According to the CDC, in the United States, non-adherence is a 100 to 300 billion dollar problem , where dose timing is rarely measured. Most of that cost doesn't show up as pharmacy spending. It shows up as avoidable hospital admissions.

For scale: 3.8 billion prescriptions are written in the US every year, and one in five new prescriptions is never even filled. And for older adults with dementia, care is projected to cost 409 billion dollars in 2026. That's a population where managing medication is especially hard.

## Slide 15

FINANCIAL IMPACT 2 OF 4

Readmission penalties make post-discharge adherence a hospital revenue issue

Up to 3%

Cut to all Medicare fee-for-service base payments for hospitals with excess readmissions

78.2%

Of hospitals penalized in FY 2026 (21.8% received no penalty)

240

Hospitals (8.1%) facing penalties of 1% or more in FY 2026, up from 208

$16,037

Mean cost of a single 30-day readmission (all conditions)

Source: CMS HRRP (https://www.cms.gov/medicare/payment/prospective-payment-systems/acute-inpatient-pps/hospital-readmissions-reduction-program-hrrp), CMS HRRP impact file guide (https://www.cms.gov/Medicare/Medicare-Fee-for-Service-Payment/AcuteInpatientPPS/Downloads/HRRP_StratMethod_ImpctFile_UG.PDF), Becker's Hospital Review (https://www.beckershospitalreview.com/finance/cms-more-hospitals-to-face-higher-readmission-penalties-in-2026/), Readmission cost meta-analysis, PMC 2024 (https://pmc.ncbi.nlm.nih.gov/articles/PMC11011876/)

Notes: Slide 15. Financial impact 2 of 4: readmission penalties (37:00 to 39:00)

For hospitals, this is a revenue issue.

Under Medicare's Hospital Readmissions Reduction Program, a hospital with too many readmissions can lose up to 3 percent of all its Medicare fee-for-service base payments, not just the payments for the readmitted patients.

In fiscal year 2026, about 78 percent of hospitals are being penalized. Only 21.8 percent got no penalty at all. 240 hospitals face penalties of 1 percent or more, up from 208 the year before.

And a single 30-day readmission costs about 16,000 dollars on average.

Here's where the product fits. A dispenser that reports missed or late doses after discharge gives the care team a signal inside that 30-day window, while there's still time to act.

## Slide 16

FINANCIAL IMPACT 3 OF 4

Adherent patients save $1,258 to $7,823 a year, against a $150 device

Source: Roebuck et al., Health Affairs 2011 (https://vbidcenter.org/wp-content/uploads/2014/11/Medication-Adherence-Leads-To-Lower-Health-Care-Use-And-Costs-Despite-Increased-Drug-Spending_Health-Affairs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), Readmission cost meta-analysis, PMC 2024 (https://pmc.ncbi.nlm.nih.gov/articles/PMC11011876/), AutomatedPillDispenser repo (https://github.com/arewa-builds/AutomatedPillDispenser)

Illustrative unit economics

Device, all-in: $100 to $150
One avoided readmission: $16,037
$16,037 ÷ $108 ≈ 107x the device cost
Benefit-cost ratios from better adherence: 3.1:1 to 10.1:1

Scenario math, not a measured outcome of this prototype.

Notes: Slide 16. Financial impact 3 of 4: savings per patient (39:00 to 41:00)

What's the value of better adherence for one patient?

A large Health Affairs study of more than 135,000 patients found that patients who took their medications as prescribed saved money every year, even after paying for the extra medication. The net savings were 7,823 dollars a year for heart failure, 3,908 for hypertension, 3,756 for diabetes, and 1,258 for high cholesterol. The return was between 3 and 10 dollars for every dollar spent.

Now compare that with the device. It costs 100 to 150 dollars. One avoided readmission, at about 16,000 dollars, is roughly 148 times the cost of the device.
To be clear, that's illustrative math, not a measured result. This prototype hasn't been tested with patients yet. But it shows why the unit economics are worth pursuing.

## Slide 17

FINANCIAL IMPACT 4 OF 4

For mild dementia, reliable medication routines can mean more years at home

Care setting (2025 US median) | Annual cost
Nursing home, private room | $129,575
Nursing home, semi-private room | $114,975
Assisted living community | $74,400
Prototype dispenser (one-time) | $100 to $150

Each year a patient stays home instead of a private nursing home room avoids up to $129,575 in facility cost.

7.4 million

Americans 65+ living with Alzheimer's dementia in 2026

75%

Of adults 50+ want to stay in their own homes for life

~3 million

Older adults admitted to nursing homes for drug-related problems, over $14B a year

9 of 18

Mild dementia users kept 100% self-administration at 3 months with a reminder device; 11 started at 0%

Source: Alzheimer's Association (CareScout 2025 medians) (https://www.alz.org/help-support/caregiving/financial-legal-planning/planning-for-care-costs), 2026 Alzheimer's Facts and Figures (https://pmc.ncbi.nlm.nih.gov/articles/PMC13098189/), AARP 2024 (https://www.aarp.org/pri/topics/livable-communities/aarp-research-insights-livable-communities/), AHRQ (https://www.ncbi.nlm.nih.gov/books/NBK2670/), Mild dementia reminder study, PMC 2023 (https://pmc.ncbi.nlm.nih.gov/articles/PMC10697399/)

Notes: Slide 17. Financial impact 4 of 4: dementia and staying at home (41:00 to 43:30)
The last point is the one I care about most: independence.
An estimated 7.4 million Americans aged 65 and older live with Alzheimer's dementia. And 75 percent of adults over 50 say they want to stay in their own homes for life.

Medication is often what breaks that. According to AHRQ, about three million older adults are admitted to nursing homes because of drug-related problems, at a cost of more than 14 billion dollars a year.

Look at the costs on the left. A private nursing home room costs a median of about 129,600 dollars a year. A semi-private room is about 115,000. Assisted living is about 74,400. The dispenser is a one-time cost of around 100 dollars.

There's encouraging evidence too. In a three-month study of 18 people with mild dementia, 11 of them were taking none of their medication independently before using a reminder device. At three months, 9 of the 18 were taking 100 percent of their doses on their own.

That's the human outcome. The patient keeps taking their own medication, and the caregiver gets data instead of daily check-in calls. Every year someone with mild dementia can safely stay at home avoids up to about 129,600 dollars in nursing home costs.

Currently, the prototype hasn't been studied with people who have dementia. This is the target use case, not a proven result.

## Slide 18

ROADMAP AND Q&A

What ships next

Safety

Bench-validate one actuation per cycle and face-departure gating on v3

Data quality

Separate bench rows from patient rows; fix anchor drift after midnight UTC

Prediction

MLflow adherence-risk model to replace the drift and rate rule

Identity

Move from face presence to patient match, plus pill color and size checks

Validation

Bench v3 drivetrain, then a supervised pilot with caregivers

Questions? github.com/arewa-builds/AutomatedPillDispenser

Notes: Slide 18. Roadmap and Q&A (43:30 to 45:00)
So what's next?
On safety, I'll validate one actuation per cycle and face-departure gating on the v3 hardware. On data quality, I'll separate bench test rows from patient rows and fix the drift calculation for doses after midnight UTC. On prediction, an MLflow adherence-risk model will replace the simple rule. On identity, I'll move from detecting that someone is present to matching the right patient, and add pill color and size checks. And for validation, I'll bench-test the v3 drivetrain and then run a supervised pilot with caregivers.
To sum up: the system works end to end, the data has already caught a real safety issue, and the roadmap is specific.
The code is all on GitHub at arewa-builds, under AutomatedPillDispenser. Thank you. I'm happy to take your questions about the data pipeline, the vision thresholds, the mechanism, or the cost model.
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

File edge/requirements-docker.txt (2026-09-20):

# Container-optimized deps (headless OpenCV — no GUI display libs required)
opencv-python-headless>=4.8.0,<5
opencv-contrib-python>=4.8.0,<5
mediapipe>=0.10.14
numpy>=2.3.0,<2.4
pyserial>=3.5

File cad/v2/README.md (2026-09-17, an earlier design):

# CAD v2 — carousel-only rotation

The v1 build failed on the bench in three specific ways. v2 is the redesign that fixes them:

| v1 bench failure | v2 fix |
| :--- | :--- |
| Internal "cross hair" ribs stopped the MG90S seating | No ribs and no servo well in the bore. The servo sits **above** the drum on a removable bridge and drives the hub straight down. |
| The drop plate rotated instead of the carousel | The plate has **three keys** that drop into notches in the drum ledge. It is mechanically incapable of turning. |
| The chute exit was a slit no tablet could pass | The exit is a **40 mm wide open trough** through a 45.6 mm window, falling at 38 deg inside and 45 deg outside. |

Everything is parametric — edit `parameters_v2.scad` and re-run `render_all_v2.sh`.

## How a dose works

1. The carousel parks with a **solid floor band** over the plate opening. Nothing can fall.
2. To dispense, the servo turns the carousel **one 60 deg step**.
3. During that step the next compartment's drop hole sweeps across the plate opening. The hole's trailing edge drags the tablets over the window and they fall.
4. Pills land on the 38 deg hopper floor, exit the drum through the wall window, run down the 45 deg external trough and land in the catch tray, where the laptop camera counts them.

### The leak rule (do not break this)

```
floor band  =  360/car_n  -  car_hole_deg      must be  >  open_deg
              (60)          (30)                         (18)
```

30 deg of band over an 18 deg opening leaves **+/- 6 deg of parking error** before a
neighbouring compartment starts dribbling pills into the chute. If you widen the
plate opening or the drop holes, re-check this inequality first. It is the reason
the plate opening is a modest window rather than a full compartment-sized sector,
and the reason each compartment floor is **ramped** — a narrower hole would
otherwise leave tablets parked on a flat ledge and short the dose.

## Servo choice — read before buying

Direct drive means one carousel step is a real 60 deg of servo output.

- **MG90S 360 deg (continuous rotation)** — recommended. Six doses per revolution, always turning the same way. Steps are timed, so calibrate `MS_PER_60_DEG` once and re-zero at every refill.
- **Standard 180 deg MG90S** — works for **three doses per fill**: park at 0 / 60 / 120 / 180, then sweep back. The return sweep re-crosses compartments 1-3, which are already empty, so nothing is lost. Fill compartments in rotation order.

Either way the hub is driven through a round horn keyed into a pocket, so the
carousel still lifts straight out of the drum for refilling.
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

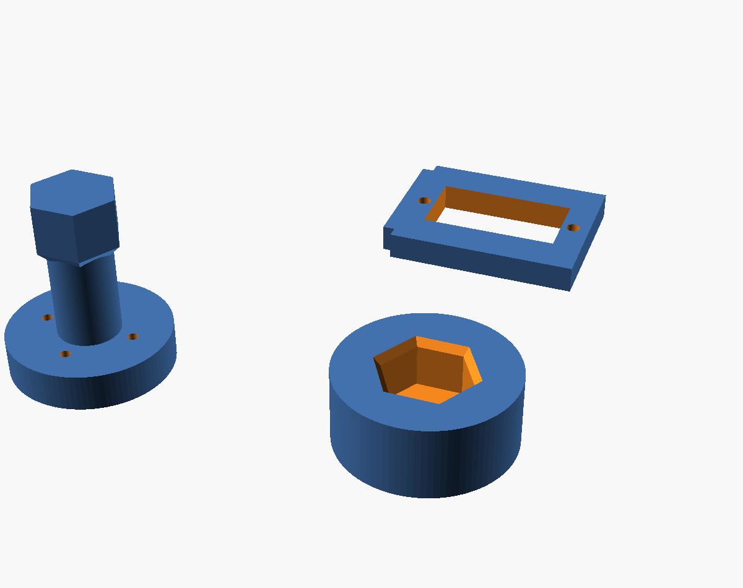
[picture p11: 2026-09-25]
cad/v3/previews/coupon_2_drive_train.png

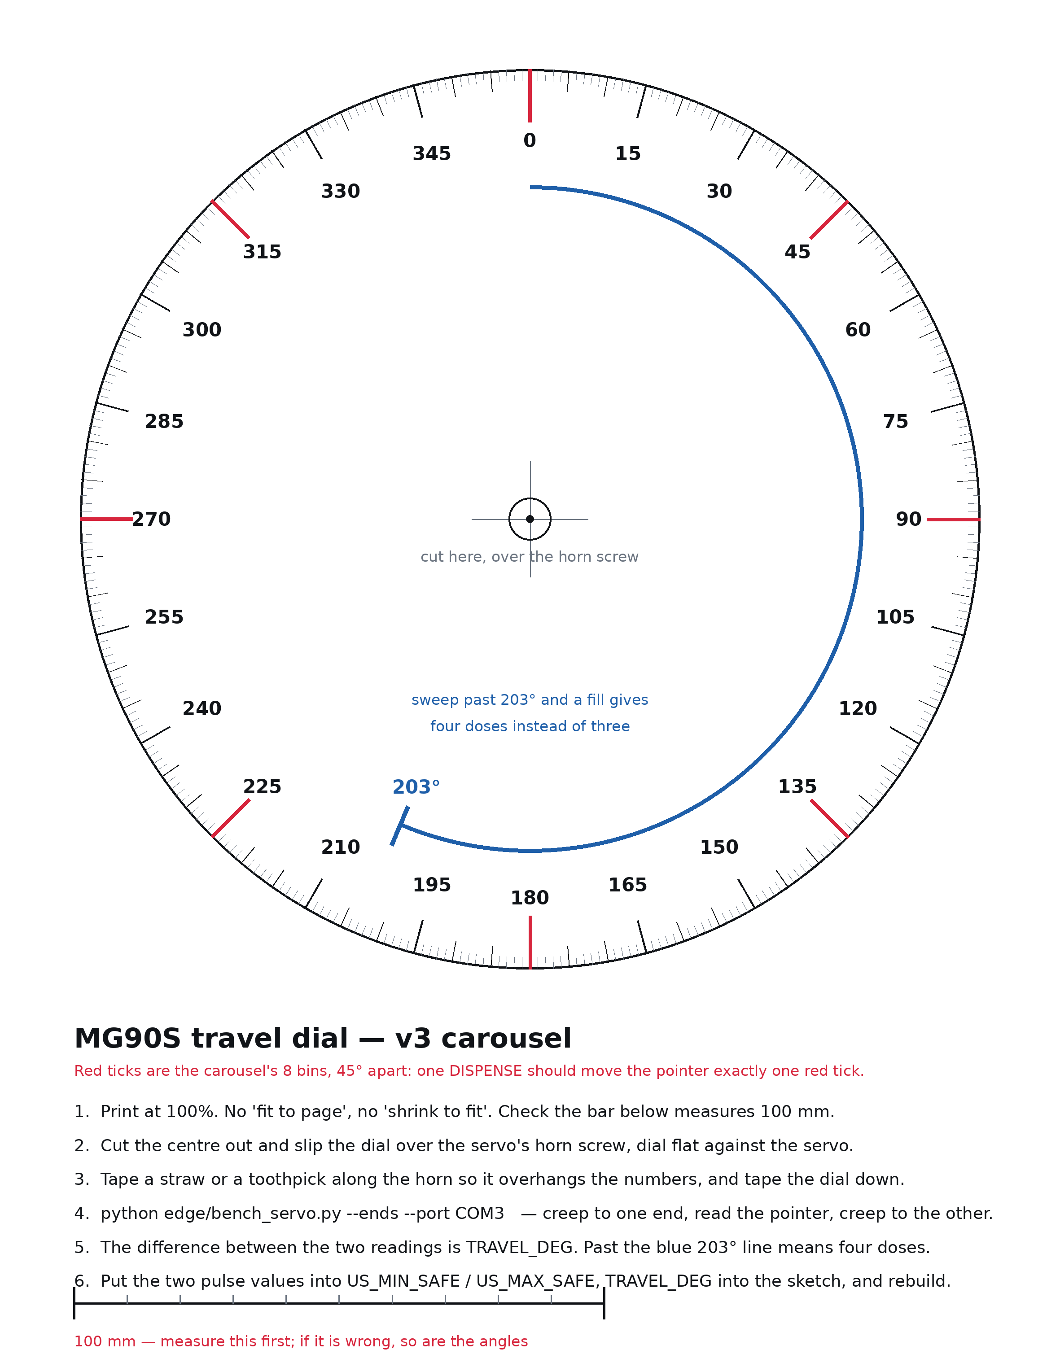
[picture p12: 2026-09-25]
docs/diagrams/servo_protractor.png

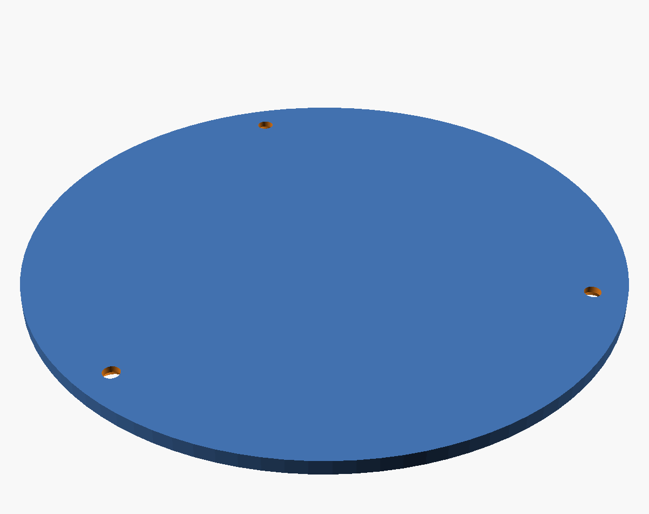
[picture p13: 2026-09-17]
cad/v3/previews/part_g3_base_cover.png

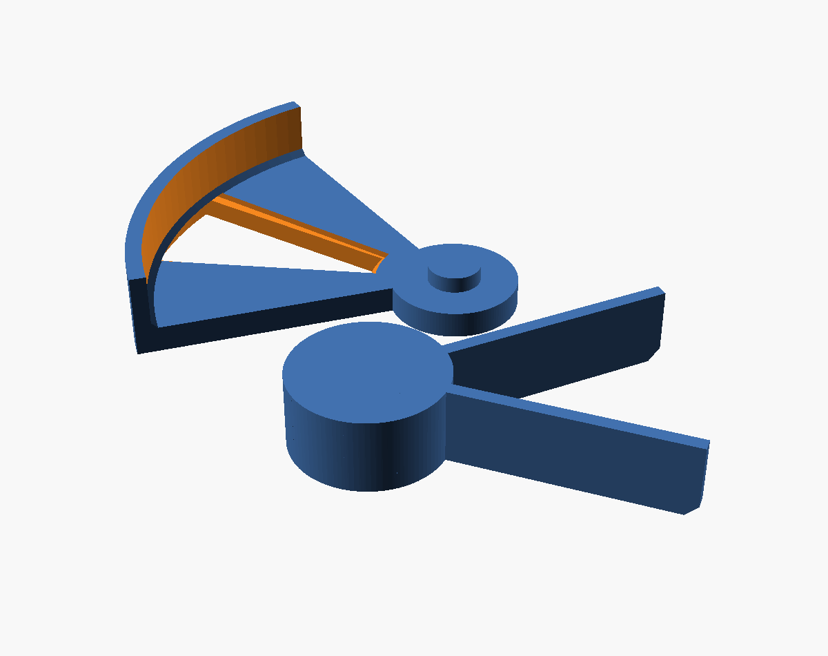
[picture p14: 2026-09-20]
cad/v3/previews/coupon_1_sector.png

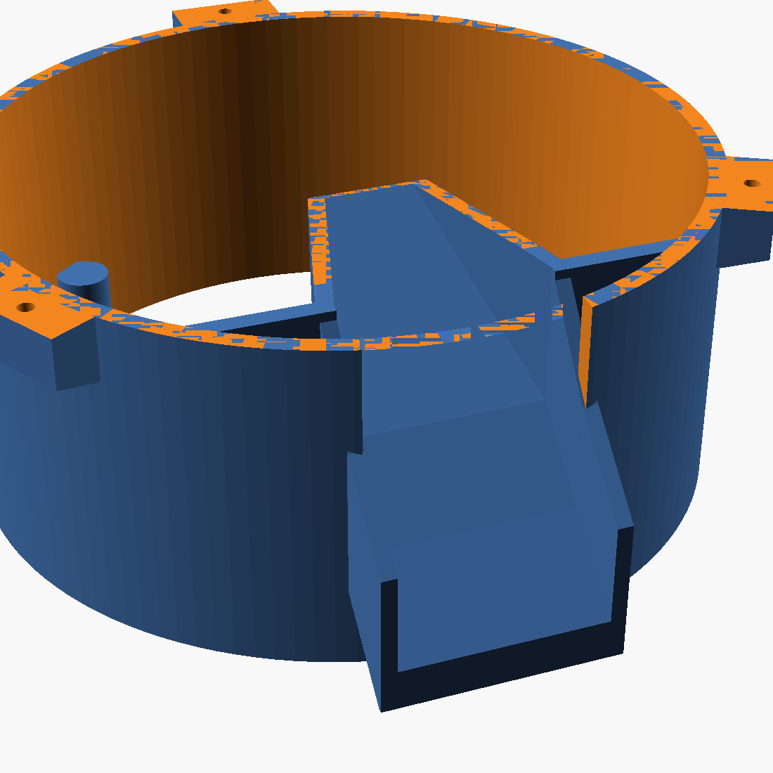
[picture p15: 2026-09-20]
cad/v3/previews/part_b3_base_body_chute.png

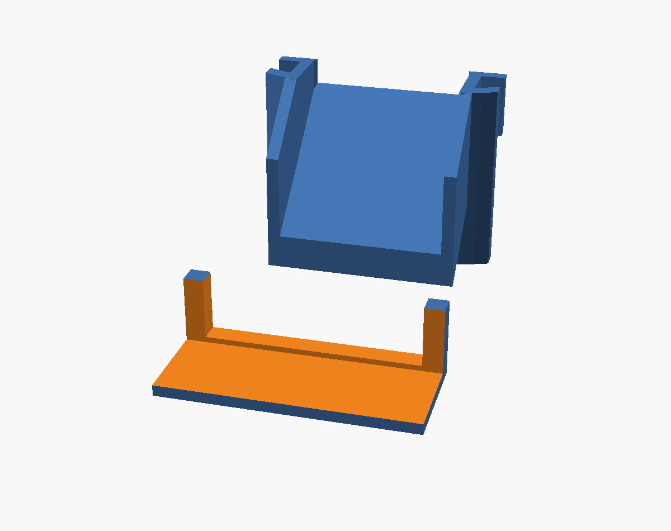
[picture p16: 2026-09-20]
cad/v3/previews/coupon_3_chute_dock.png

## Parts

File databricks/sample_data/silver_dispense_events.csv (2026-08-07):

event_ts_utc | patient_id | face_match_confidence | pills_detected | dispense_latency_ms | event_status | hardware_source | retry_count | is_success | scheduled_window | time_drift_minutes
2026-08-24T08:01:21Z | patient_demo_001 | 0.7861 | 1 | 565 | success | mock | 0 | True | morning | 1.35
2026-08-24T20:01:26Z | patient_demo_001 | 0.8794 | 1 | 345 | success | mock | 0 | True | evening | 1.43
2026-08-25T08:03:11Z | patient_demo_001 | 0.7272 | 1 | 687 | success | serial | 0 | True | morning | 3.18
2026-08-25T20:03:28Z | patient_demo_001 | 0.9547 | 1 | 606 | success | serial | 0 | True | evening | 3.47
2026-08-26T08:06:43Z | patient_demo_001 | 0.9261 | 1 | 489 | success | mock | 0 | True | morning | 6.72
2026-08-26T20:06:48Z | patient_demo_001 | 0.883 | 1 | 368 | success | serial | 0 | True | evening | 6.8
2026-08-27T08:10:08Z | patient_demo_001 | 0.7413 | 1 | 880 | success | serial | 0 | True | morning | 10.13
2026-08-27T20:10:13Z | patient_demo_001 | 0.8985 | 1 | 872 | retry | mock | 1 | True | evening | 10.22
2026-08-28T08:12:12Z | patient_demo_001 | 0.9452 | 1 | 613 | success | serial | 0 | True | morning | 12.2
2026-08-28T20:12:45Z | patient_demo_001 | 0.9729 | 1 | 426 | success | mock | 0 | True | evening | 12.75
2026-08-29T08:16:08Z | patient_demo_001 | 0.8225 | 1 | 1590 | success | mock | 0 | True | morning | 16.13
2026-08-29T20:16:27Z | patient_demo_001 | 0.7351 | 1 | 345 | success | serial | 0 | True | evening | 16.45
2026-08-30T08:18:51Z | patient_demo_001 | 0.9746 | 1 | 924 | success | mock | 0 | True | morning | 18.85
2026-08-30T20:19:23Z | patient_demo_001 | 0.8936 | 1 | 572 | success | serial | 0 | True | evening | 19.38

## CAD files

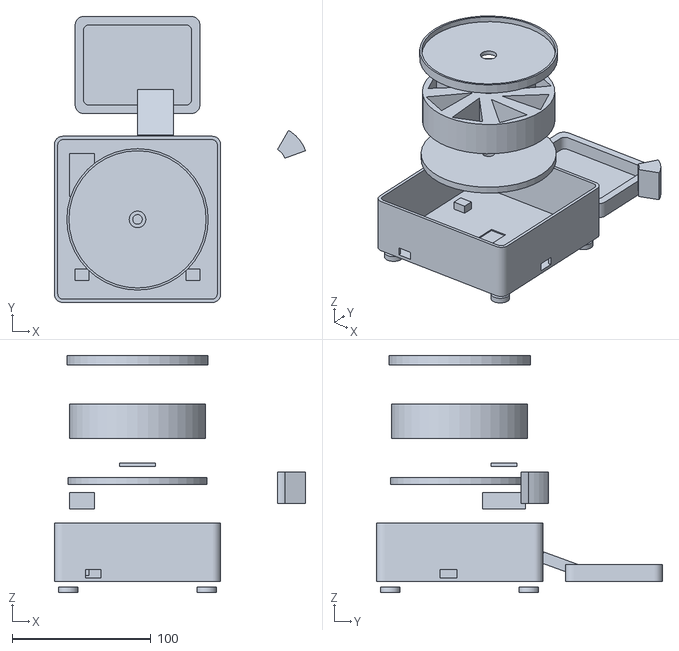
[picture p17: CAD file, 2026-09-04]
cad/stl/assembly_preview.stl
181.3 x 206.4 x 171.2

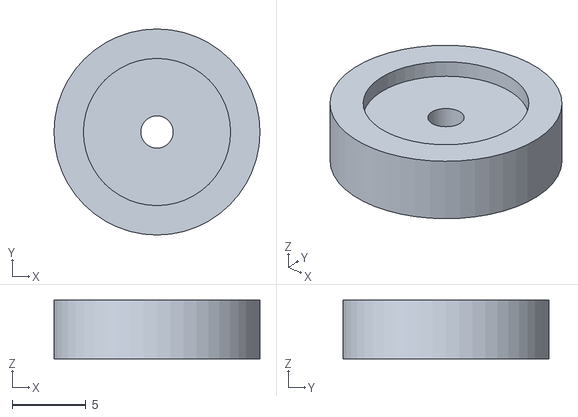
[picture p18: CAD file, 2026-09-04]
cad/stl/part_j_foot.stl
14.0 x 14.0 x 4.00

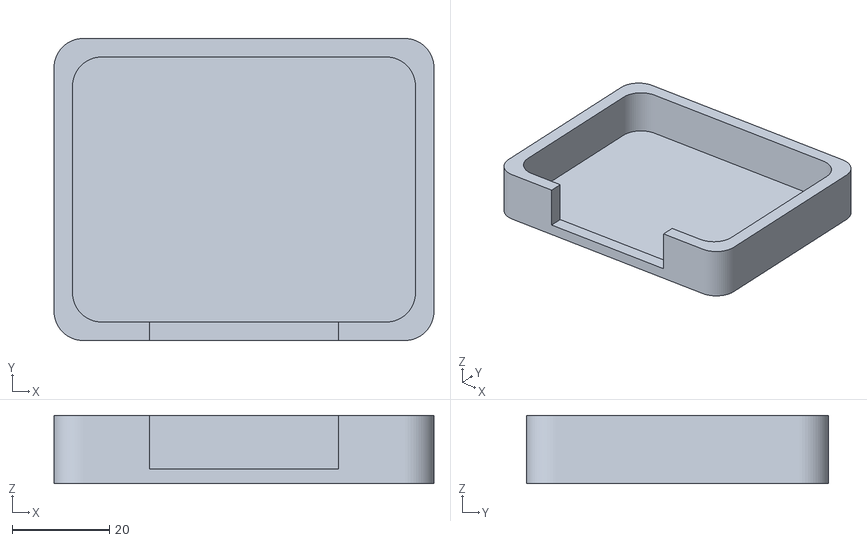
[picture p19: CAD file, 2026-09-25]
cad/v3/stl/part_f3_catch_tray.stl
78.0 x 62.0 x 14.0

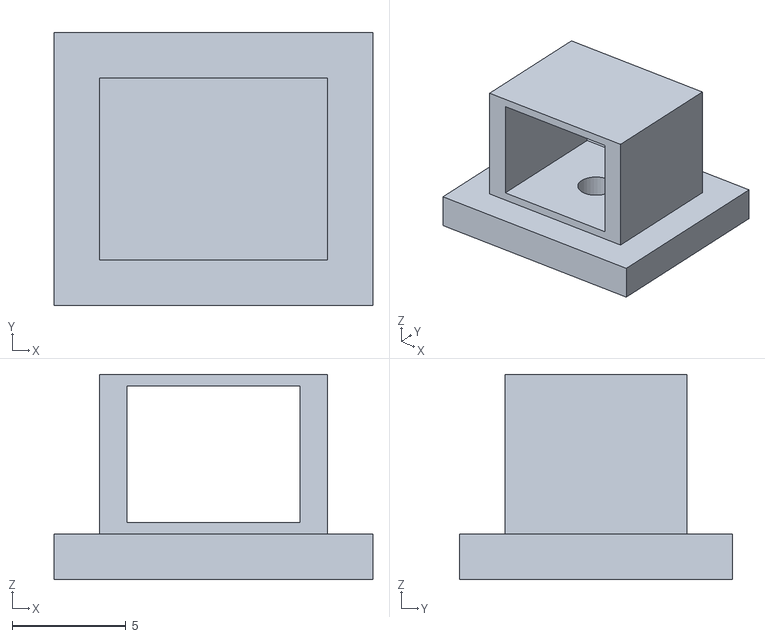
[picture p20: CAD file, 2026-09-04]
cad/stl/part_i_cable_clip.stl
14.0 x 12.0 x 9.00

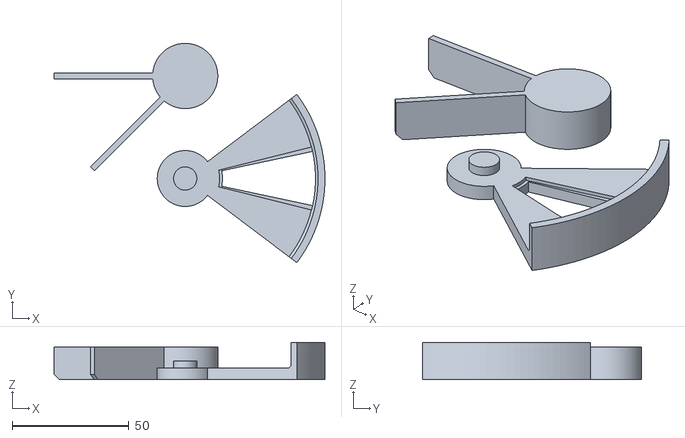
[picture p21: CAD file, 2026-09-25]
cad/v3/stl/coupon_1_sector.stl
116.3 x 94.1 x 16.0

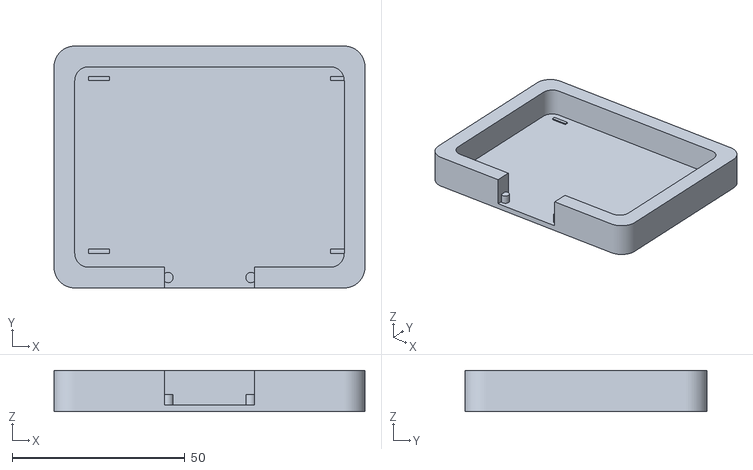
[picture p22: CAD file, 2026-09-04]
cad/stl/part_f_catch_tray.stl
90.0 x 70.0 x 12.0

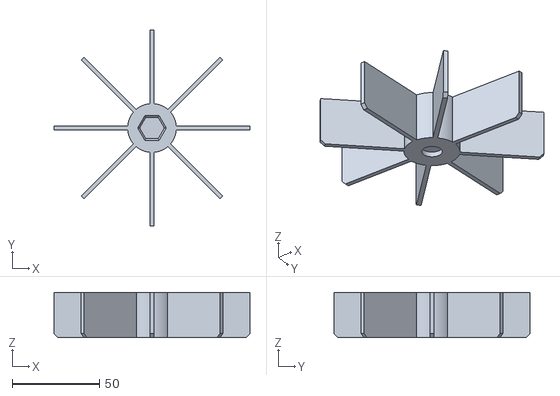
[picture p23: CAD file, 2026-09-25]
cad/v3/stl/part_c3_carousel.stl
112.6 x 112.6 x 26.0

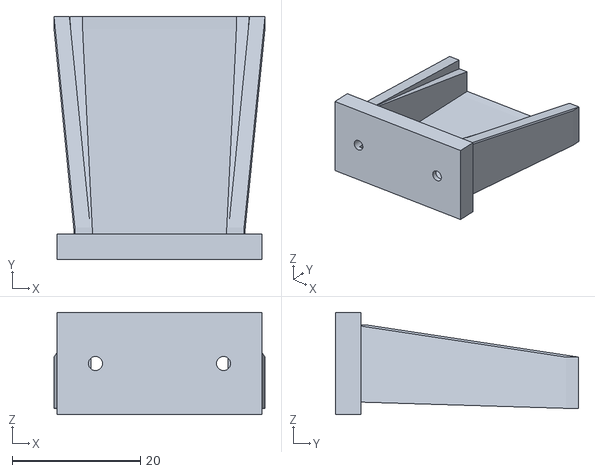
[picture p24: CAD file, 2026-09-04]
cad/stl/part_g_chute_spout.stl
32.9 x 38.0 x 16.0

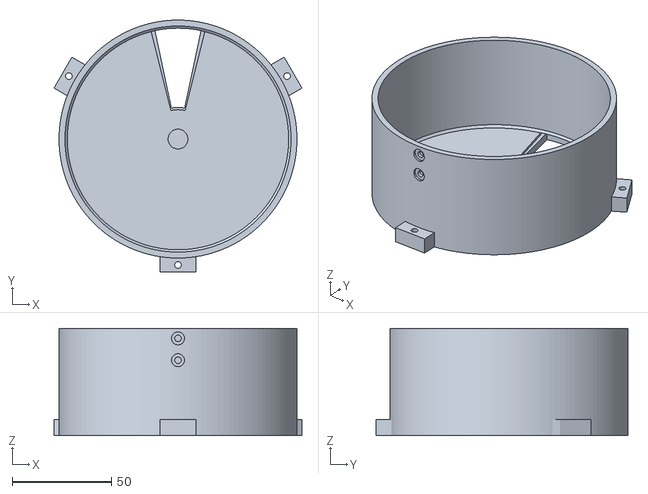
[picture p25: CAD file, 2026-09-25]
cad/v3/stl/part_a3_deck_body.stl
125.0 x 127.0 x 54.0

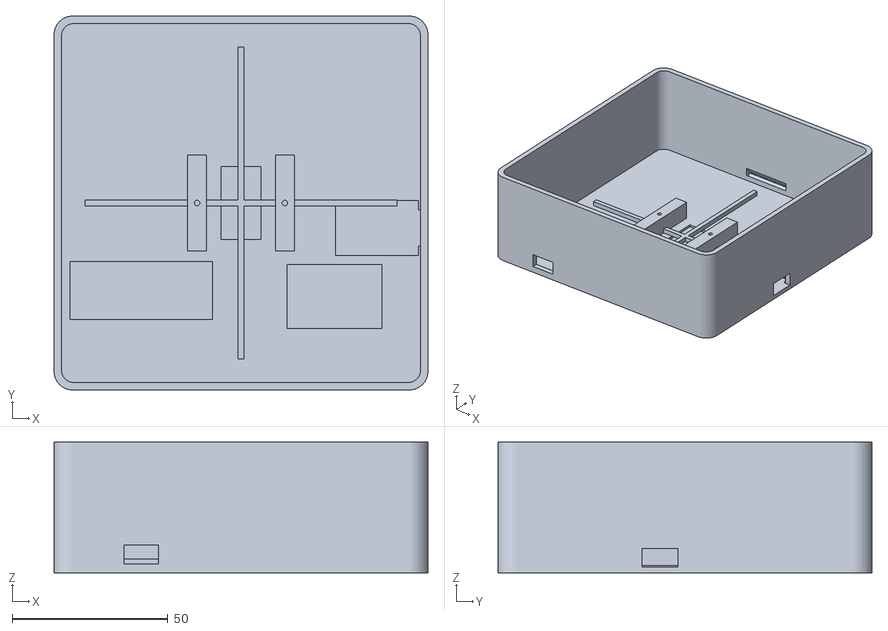
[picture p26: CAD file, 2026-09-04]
cad/stl/part_a_base_enclosure.stl
120.0 x 120.0 x 42.0

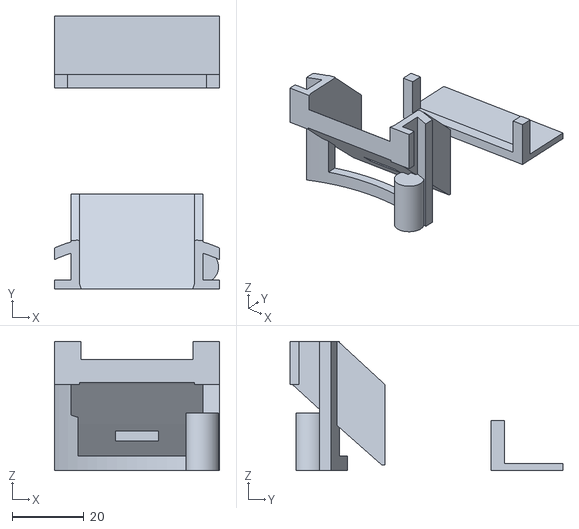
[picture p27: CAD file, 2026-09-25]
cad/v3/stl/coupon_3_chute_dock.stl
46.0 x 76.0 x 36.0

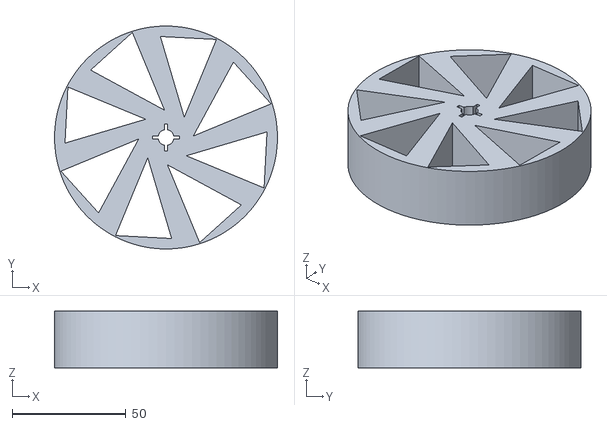
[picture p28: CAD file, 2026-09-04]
cad/stl/part_c_carousel.stl
98.0 x 98.0 x 25.0

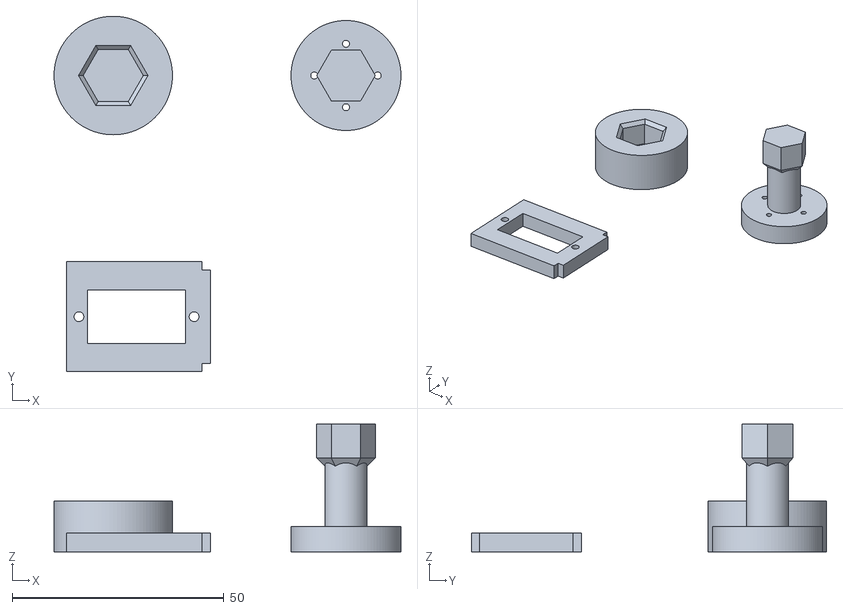
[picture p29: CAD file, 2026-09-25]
cad/v3/stl/coupon_2_drive_train.stl
82.0 x 84.0 x 30.2

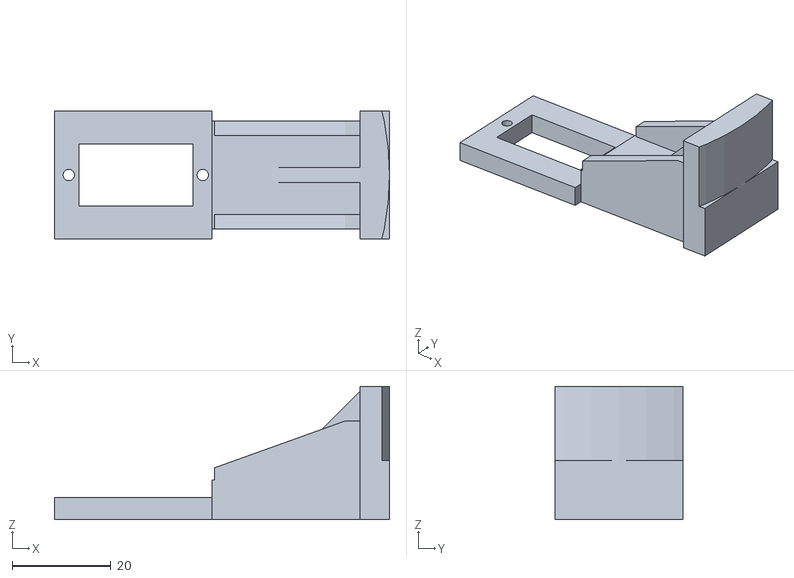
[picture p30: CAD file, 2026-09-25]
cad/v3/stl/part_e3_servo_bracket.stl
68.0 x 26.0 x 27.0

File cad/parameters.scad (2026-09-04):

// Shared parametric dimensions — Automated Pill Dispenser (full prototype print set)
// include <parameters.scad>;

// ----- Global print / fit -----
layer_h         = 0.2;
nozzle_d        = 0.4;
wall            = 2.4;
clearance_slip  = 0.30;
clearance_press = 0.08;

// ----- Arduino Nano 33 BLE -----
nano_l = 45.0;
nano_w = 18.0;
nano_h = 7.0;
nano_usb_w = 9.0;
nano_usb_h = 4.0;

// ----- MG90S servo -----
servo_l = 22.8;
servo_w = 12.2;
servo_h = 28.5;
servo_tab_l = 32.2;
servo_horn_od = 7.0;
servo_shaft_clear_d = 9.0;

// ----- LiPo + TP4056 -----
lipo_l = 30.0;
lipo_w = 20.0;
lipo_h = 6.0;
tp4056_l = 26.0;
tp4056_w = 17.0;
tp4056_h = 5.0;
tp4056_usbc_w = 9.5;
tp4056_usbc_h = 4.0;

// ----- Part A enclosure -----
base_outer_xy = 120.0;
base_outer_h  = 42.0;
chute_angle   = 45.0;
chute_w       = 22.0;

// ----- Part B plate -----
base_plate_dia = 100.0;
base_plate_h   = 5.0;
drop_w         = 20.0;
drop_d         = 15.0;
drop_r_offset  = 32.0;

// ----- Part C carousel -----
car_dia     = 98.0;
car_h       = 25.0;
car_pockets = 8;
car_wall    = 2.0;
car_hub_od  = 18.0;
car_hub_id  = servo_horn_od - clearance_press;

// ----- Part D latch gate -----
gate_travel    = 22.0;
gate_thickness = 2.4;
gate_w         = drop_w + 6.0;
gate_l         = drop_d + gate_travel + 8.0;

// ----- Part E carousel lid -----
lid_dia        = car_dia + 4.0;
lid_h          = 3.0;
lid_lip_h      = 6.0;
lid_clearance  = 0.5;

// ----- Part F catch tray (vision landing zone) -----
tray_l = 90.0;
tray_w = 70.0;
tray_h = 12.0;
tray_floor = 2.0;
tray_well_margin = 6.0;

// ----- Part G chute spout -----
spout_len = 35.0;
spout_flare = 28.0;

// ----- Part H latch servo bracket -----
bracket_wall = 2.4;

// ----- Part I cable clips -----
clip_w = 10.0;
clip_span = 6.0;

// ----- Part J feet -----
foot_od = 14.0;
foot_h  = 4.0;

// ----- Part K pill pocket insert (optional reducer) -----
insert_h = car_h - 2.0;
insert_outer_clear = 0.35;

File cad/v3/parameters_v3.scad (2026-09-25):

// ============================================================================
// Automated Pill Dispenser — v3 "integral deck + open carousel"
// Shared parametric dimensions.   include <parameters_v3.scad>;
//
// z = 0 is the underside of the base body; the base cover hangs below it, so
// the table plane is z = base_z. +Y is the front (chute, tray, camera).
//
// Mechanism: the deck holds the pills in. It has ONE wedge opening. The unit
// parks with the JUST-EMPTIED compartment sitting over that opening, so
// nothing can leak; a 45 deg step sweeps the next compartment across the
// opening and gravity empties it. One servo, no gate, no carousel floor.
//
// Sizing rule that makes the park state leak-proof: the opening's angular
// width must fit inside one compartment's interior with margin to spare, at
// the opening's INNER radius (where a divider subtends the most angle):
//
//     open_deg  <=  360/car_n - 2*asin(div_t / (2*open_r_in)) - 2*park_margin
//     24        <=  45        - 8.6                           - 2*6.2
//
// Widening the opening or moving it inward eats the parking margin.
// ============================================================================

// ---------------------------------------------------------------- print / fit
layer_h        = 0.2;
nozzle_d       = 0.4;
wall           = 3.0;
fit_slip       = 0.35;
fit_press      = 0.10;
m3_pilot_d     = 2.55;
m3_free_d      = 3.35;
m2_pilot_d     = 1.65;
m2_free_d      = 2.30;

// ---------------------------------------------------------------- drum
h_od           = 120.0;
h_id           = h_od - 2 * wall;          // 114
h_ri           = h_id / 2;                 // 57
// Top of the deck body wall. Both bracket screws have to land in wall that sits
// above the carousel's sweep, so this is set by brk_screw_z, not by looks.
rim_z          = 106.0;

// ---------------------------------------------------------------- deck (A3)
deck_z         = 52.0;                     // deck underside / body split plane
deck_t         = 5.0;                      // structural: the deck IS the drum
deck_top       = deck_z + deck_t;          // 57
deck_fillet    = 1.2;                      // fillet where the wall meets the deck

// The one opening.
open_deg       = 24.0;
open_r_in      = 16.0;
open_r_out     = h_ri;                     // breaches the bore: nothing rides past
open_ctr       = 90.0;                     // front (+Y)
open_relief    = 1.2;                      // lead-in relief on the deck top face

// Centre pilot: the carousel's only bearing. Post on the deck, journal in the
// hub, so the drive shaft never carries weight.
pilot_d        = 10.0;
pilot_engage   = 2.75;

// Body joint: three ears outside the drum. Concentricity between bodies is not
// critical — the running surface and the bore are both on the deck body.
ear_angles     = [30, 150, 270];
ear_w          = 18.0;
ear_out        = 7.0;
ear_t          = 8.0;

// ---------------------------------------------------------------- carousel (C3)
car_n          = 8;
car_pitch      = 360 / car_n;              // 45
car_od         = h_id - 1.4;               // 112.6 -> 0.7 mm sweep gap per side
car_r          = car_od / 2;
div_t          = 2.4;
div_h          = 26.0;
div_chamfer    = 1.6;                      // clears the deck/wall fillet
hub_od         = 28.0;
car_gap        = 0.35;                     // divider to deck running gap
car_z          = deck_top + car_gap;       // 57.35
car_top        = car_z + div_h;            // 83.35
pilot_post_h   = car_gap + pilot_engage;   // 3.1
pilot_bore_d   = pilot_d + fit_slip;       // 10.35

// Derived parking margin, echoed by the parts so a bad edit is loud.
park_margin    = (car_pitch - 2 * asin(div_t / (2 * open_r_in)) - open_deg) / 2;

// ---------------------------------------------------------------- drive train
// Hex socket, deliberately loose: it passes torque but cannot side-load the
// carousel, so the pilot post alone defines the axis.
//
// The looseness costs rotational play, though, and that play lands directly on
// the park angle: a forward step ends with the driving flats in contact, so the
// carousel parks that much behind its stop. A 7 mm hex at 0.4 mm slip gives
// +/- 6.28 deg, which is the whole park margin on its own. Widening the hex buys
// the accuracy back without tightening the fit, since the play goes as slip over
// size: 12 mm at 0.3 mm slip is +/- 2.58 deg and still a fit you can drop in.
hex_af         = 12.0;
hex_slip       = 0.30;
hex_depth      = 8.0;
hex_corner_d   = hex_af / cos(30);
hex_backlash   = 30 - acos(((hex_af + hex_slip) / 2) / (hex_corner_d / 2));

shaft_body_d   = 10.0;
shaft_head_d   = 26.0;
shaft_head_t   = 6.0;

// MG90S
servo_l        = 22.8;
servo_w        = 12.2;
servo_case_h   = 22.5;
servo_tab_span = 32.2;
servo_tab_t    = 2.5;
servo_shaft_in = 5.9;
servo_nose_h   = 6.0;
servo_shaft_h  = 4.7;

horn_disc_d    = 20.4;
horn_disc_h    = 4.2;
horn_hole_r    = 7.5;
horn_screw_n   = 4;
horn_boss_d    = 8.5;

// ---------------------------------------------------------------- bracket (E3)
brk_ctr        = 270.0;                    // rear wall, opposite the chute
brk_pad_w      = 26.0;
brk_pad_t      = 6.0;
brk_arm_w      = 22.0;
brk_arm_t      = 8.0;
brk_arm_top    = 112.0;                    // = the servo flange plane
brk_arm_z0     = brk_arm_top - brk_arm_t;  // 104, the arm's underside
// The pad stands 6 mm off the bore, so below car_top it would sit squarely in the
// ring the dividers sweep and the carousel could not turn at all. Everything the
// bracket puts inside the bore is therefore derived off car_top, and the wall is
// tall enough (rim_z) to take both screws above that line.
brk_clear      = 1.65;                     // pad underside to divider top
brk_pad_z0     = car_top + brk_clear;      // 85
brk_pad_h      = brk_arm_top - brk_pad_z0; // 27, pad runs up to the flange plane
brk_screw_z    = [brk_pad_z0 + 5, rim_z - 5];   // [90, 101], through the wall
// The servo plate has to be thinner than the servo's nose (6 mm from flange to
// case top) or the drive shaft's head fouls it. The beam keeps its full depth.
brk_head_t     = 4.5;
brk_rib_h      = 12.0;
// Gusset depth is whatever fits between the arm and the pad's foot, less 1 mm so
// its lower tip never reaches the sweep either.
brk_web_h      = brk_arm_z0 - brk_pad_z0 - 1.0;   // 18

// ---------------------------------------------------------------- chute (B3)
chute_wall     = 2.4;
// The pill passage plus 0.4 mm, so the notch's cut faces land inside the chute's
// side walls rather than coplanar with their inner faces. The notch subtracts
// the chute solid, so those walls keep their full 2.4 mm and still overlap the
// drum wall by 2.0 mm — that overlap is what fuses the chute into the housing.
chute_win_w    = 32.8;
// The notch is cut as a box MINUS the ramp solid, so it can never breach the
// floor. z0 leaves a hoop strip along the bottom of the wall — it closes the
// first layers into a full ring when printing and stiffens the two wall ends
// either side of the notch. It sits well below the ramp's underside.
chute_win_z0   = 4.0;
chute_win_z1   = deck_z;

// [ y, floor top z, inside width, side-wall top z, floor thickness ]
// The floor thickens toward the exit so its UNDERSIDE runs at 40-42 deg rather
// than following the 38-40 deg top surface: it keeps the overhang printable and
// puts the material where the chute cantilevers out of the wall.
// Station 0 sits at y = 14, inside the wedge's inner radius of 16, so the ramp
// underlaps the opening: every pill through the wedge lands on ramp, never on
// the ramp's leading edge.
chute_stations = [
    [17.0, 52.0, 14.0, 51.9, 2.4],
    [45.0, 30.0, 32.0, 51.8, 6.0],
    [57.0, 19.0, 32.0, 36.0, 6.0],
    [70.0,  8.0, 32.0, 24.0, 6.5],
];

// ---------------------------------------------------------------- tray (F3)
tray_y0        = 68.0;
tray_l         = 62.0;
tray_w         = 78.0;
tray_floor     = 2.0;
tray_h         = 14.0;
tray_mouth_h   = 3.0;                      // cut-down wall, 1.5 mm under the chute lip

// ---------------------------------------------------------------- base (G3)
base_t         = 3.0;
base_z         = -base_t;                  // table plane
post_d         = 9.0;
post_r         = h_ri - post_d / 2 + 0.8;
post_angles    = [70, 190, 310];
cable_w        = 12.0;
cable_h        = 6.0;
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

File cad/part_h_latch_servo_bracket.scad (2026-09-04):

// Part H — Dedicated latch MG90S mounting bracket
// Mounts secondary servo beside drop hole to drive Part D gate.
// Export → stl/part_h_latch_servo_bracket.stl
// Print flat on back plate. No supports.

include <parameters.scad>;

$fn = 48;

module part_h_latch_servo_bracket() {
    body_l = servo_l + 12;
    body_w = servo_w + 2 * bracket_wall + 2;
    body_h = 14;

    difference() {
        union() {
            // Back plate (screws to Part A side wall or plate post)
            translate([0, 0, 1.2])
                cube([body_w + 16, body_l + 4, 2.4], center = true);
            // Cradle around servo body
            translate([0, 0, body_h / 2])
                cube([body_w, body_l, body_h], center = true);
            // Horn clearance tower toward gate
            translate([body_w / 2 + 6, body_l / 2 - 4, 8])
                cube([14, 8, 10], center = true);
        }
        // Servo cavity
        translate([0, 0, body_h / 2 + 1])
            cube([servo_w + clearance_slip * 2, servo_l + clearance_slip * 2, body_h + 2], center = true);
        // Wire exit
        translate([0, -body_l / 2, 6])
            cube([8, 10, 6], center = true);
        // Tab screw holes (MG90S mounting ears)
        for (y = [-servo_tab_l / 2 + 3, servo_tab_l / 2 - 3])
            translate([0, y, body_h - 2])
                cylinder(h = 8, d = 1.8, center = true);
        // Bracket-to-housing screws
        for (x = [-(body_w / 2 + 5), (body_w / 2 + 5)])
            translate([x, 0, 1.2])
                cylinder(h = 6, d = 2.2, center = true);
        // Horn shaft clearance
        translate([body_w / 2 + 6, body_l / 2 - 4, 10])
            cylinder(h = 12, d = 10, center = true);
    }
}

part_h_latch_servo_bracket();

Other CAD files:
cad/stl/part_e_carousel_lid.stl
cad/v3/stl/part_g3_base_cover.stl
cad/stl/part_b_base_plate.stl
cad/v3/stl/part_d3_drive_shaft.stl
cad/v3/coupon_2_drive_train.scad
cad/assembly_preview.scad
cad/part_a_base_enclosure.scad
cad/part_b_base_plate.scad
cad/part_c_carousel.scad
cad/part_d_latch_gate.scad
cad/part_e_carousel_lid.scad
cad/part_f_catch_tray.scad
cad/part_g_chute_spout.scad
cad/part_i_cable_clips.scad
cad/part_j_feet.scad
cad/part_k_pill_insert.scad
cad/stl/part_d_latch_gate.stl
cad/stl/part_d_latch_horn_arm.stl
cad/stl/part_h_latch_servo_bracket.stl
cad/stl/part_k_pill_insert.stl
cad/v2/assembly_preview_v2.scad
cad/v2/lib_v2.scad
cad/v2/parameters_v2.scad
cad/v2/part_a2_housing.scad
cad/v2/part_b2_fixed_plate.scad
cad/v2/part_c2_carousel.scad
cad/v2/part_d2_drop_chute.scad
cad/v2/part_e2_servo_bridge.scad
cad/v2/part_f2_catch_tray.scad
cad/v2/part_g2_base_cover.scad
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

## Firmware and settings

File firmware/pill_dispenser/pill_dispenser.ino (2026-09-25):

/*
 * Automated Pill Dispenser — Arduino Nano 33 BLE
 * Firmware for the v3 mechanism: one positional MG90S, direct drive, no gate.
 *
 * How the v3 machine dispenses (see cad/v3/PLAN.md sections 2 and 13):
 *   The deck holds the pills in and has one 24 deg wedge opening. The unit rests
 *   with the JUST-EMPTIED compartment centred on that opening, so nothing sits
 *   above the opening between doses. A 45 deg step sweeps the next compartment
 *   across the opening and gravity empties it down the chute into the tray.
 *
 * Everything here follows from one number: parking has only +/- 6.2 deg of margin
 * before the opening's edge slips past a divider and starts draining the NEXT
 * compartment, which would be a silent double dose. Three things spend that
 * margin and the sketch has to manage all three.
 *
 *   1. Where the horn happened to land. The output spline indexes in 17.1 deg
 *      teeth (14.4 on a 25-tooth servo), the hub's hex in 60 deg and the horn
 *      screws in 90 deg, so assembly alone can leave the carousel up to 8.6 deg
 *      off centre. Nothing mechanical adjusts finer than that, so the sketch has
 *      to: TRIM and JOG shift the whole stop table at run time, and the authority
 *      reserved for them is TRIM_RANGE_DEG.
 *
 *   2. The coupling's play. The hex is loose on purpose — it must pass torque
 *      without side-loading the carousel — which costs +/- 2.58 deg of rotational
 *      play. A move ends with the driving flats in contact, so the carousel trails
 *      the shaft by that much in whichever direction it last moved. The sketch
 *      commands the shaft that far PAST the stop so the carousel lands ON it.
 *
 *   3. The servo's own positioning error, about a degree, which is what is left.
 *
 * Because 1 and 2 have to be reserved at BOTH ends of the travel, doses per fill
 * is derived from the servo's measured travel rather than assumed:
 *
 *      DOSES_PER_FILL = (TRAVEL_DEG - 2 * HEADROOM_DEG) / STEP_DEG
 *
 * A nominal 180 deg servo gives three. Measure 203 deg or more — many MG90S reach
 * about 200 between 500 and 2500 us — and the fourth comes back on its own. The
 * commissioning procedure is in firmware/README.md, and the sketch reports what it
 * derived in its CAL banner and in STATUS, so a log always records which it was.
 *
 * Angles go out as pulse widths, not degrees. write() quantises to 1 deg (about
 * 10 us) and pins the range to whatever the core's 544-2400 us mapping happens to
 * be; this margin cannot afford either.
 *
 * Moves are ramped, not stepped. A bare write() makes the servo slam the full
 * 45 deg at maximum speed, which is the peak-current case on a small cell, the
 * peak-torque case on a printed PLA coupling, and the case most likely to overrun
 * a stop on inertia. SLEW_DEG_PER_S sets the rate and the move's own duration
 * follows from it, so the timing and the motion cannot disagree.
 *
 * The servo holds its angle mechanically when unpowered, so the carousel's
 * position survives a power cycle but this sketch's idea of it does not. On boot
 * it assumes stop 0 and does not move, which is correct if you refill the way
 * cad/v3/README.md describes (return to stop 0, then refill). If the host knows
 * better — it logged every dose — it can correct the belief with SETSTOP without
 * moving anything.
 *
 * Serial protocol @ 115200. A superset of the previous one, so existing hosts
 * that only speak DISPENSE / ACK_DISPENSE keep working:
 *   Host -> "DISPENSE\n"    Device -> "ACK_DISPENSE"
 *                                     "ERR_BUSY"            mid-cycle
 *                                     "ERR_MAGAZINE_EMPTY"  last stop reached
 *   Host -> "REZERO\n"      Device -> "ACK_REZERO" | "ERR_BUSY"
 *   Host -> "SETSTOP n\n"   Device -> "ACK_SETSTOP" | "ERR_ARG" | "ERR_BUSY"
 *   Host -> "TRIM d\n"      Device -> "ACK_TRIM <deg>" | "ERR_ARG" | "ERR_BUSY"
 *   Host -> "JOG d\n"       Device -> "ACK_TRIM <deg>" | "ERR_ARG" | "ERR_BUSY"
 *   Host -> "PULSE us\n"    Device -> "ACK_PULSE <us>" | "ERR_ARG" | "ERR_BUSY"
 *   Host -> "STATUS\n"      Device -> "STATE=s STOP=i/n ANGLE=d US=u TRIM=t DOSES=n"
 *   Host -> "PING\n"        Device -> "PONG"
 *
 * PULSE is for commissioning: it ramps to a raw pulse anywhere in 500-2500 us so
 * the servo's own ends and travel can be measured with nothing but this sketch, and
 * it then marks the magazine spent so a stray DISPENSE cannot follow a hand-jogged
 * position. REZERO or SETSTOP re-establishes where the carousel is.
 *
 * TRIM sets the offset and JOG nudges it. Both re-seat the carousel on the stop it
 * is already on, so you can watch the wedge while you calibrate, and both answer
 * only once it has settled there. The value lives in RAM: the host is expected to
 * log it and send it back on connect.
 *
 * Pin map (PWM-capable on Nano 33 BLE):
 *   D9  -> carousel MG90S signal
 *   GND -> servo GND (common with Nano GND)
 *   5V  -> servo VCC. An MG90S is rated 4.8-6 V, so feed it 5 V with a bulk
 *          capacitor across it rather than the bare 3.7 V cell, and never from the
 *          Nano's 3.3 V rail.
 *
 * D10 drove the v1 latch servo. v3 has no latch — the park convention replaces
 * it — so the pin is free.
 */

#include <Servo.h>

#include "v3_geometry.h"

// ----- Pins -----
const uint8_t PIN_CAROUSEL = 9;

// ----- Geometry, generated from cad/v3/parameters_v3.scad -----
constexpr uint8_t CAROUSEL_BINS = V3_CAROUSEL_BINS;
constexpr float STEP_DEG = V3_STEP_DEG;                    // one compartment
constexpr float PARK_MARGIN_DEG = V3_PARK_MARGIN_DEG;      // how far off park may be
constexpr float COUPLING_PLAY_DEG = V3_COUPLING_PLAY_DEG;  // the loose hex's play

static_assert(STEP_DEG * CAROUSEL_BINS == 360.0f,
              "step and bin count disagree: regenerate v3_geometry.h");
static_assert(COUPLING_PLAY_DEG < PARK_MARGIN_DEG,
              "the coupling's play alone exceeds the park margin");

/*
 * ----- Servo calibration: MEASURED per unit, see firmware/README.md -----
 *
 * US_MIN_SAFE / US_MAX_SAFE are pulse widths just inside where this servo stops
 * moving, backed off far enough that it never buzzes against its own end stops.
 * TRAVEL_DEG is how far the output actually turns between them. The defaults are
 * a deliberately modest servo; commissioning replaces them with measurements.
 */
constexpr int US_MIN_SAFE = 600;
constexpr int US_MAX_SAFE = 2400;
constexpr float TRAVEL_DEG = 180.0f;
constexpr float US_PER_DEG = (US_MAX_SAFE - US_MIN_SAFE) / TRAVEL_DEG;

// Authority left for TRIM/JOG: the horn's teeth are 17.1 deg, so half a tooth is
// the worst assembly offset a trim has to absorb.
constexpr float TRIM_RANGE_DEG = 9.0f;

// Reserved at BOTH ends of the travel: a trim can push the table either way, and
// the play take-up adds to whichever end the move came from.
constexpr float HEADROOM_DEG = TRIM_RANGE_DEG + COUPLING_PLAY_DEG;

constexpr uint8_t DOSES_PER_FILL =
    static_cast<uint8_t>((TRAVEL_DEG - 2.0f * HEADROOM_DEG) / STEP_DEG);

static_assert(DOSES_PER_FILL >= 1,
              "calibrated travel cannot fit one step plus its trim headroom");
static_assert(DOSES_PER_FILL <= CAROUSEL_BINS,
              "more stops than compartments: a sweep would revisit a bin");
static_assert(2.0f * HEADROOM_DEG + DOSES_PER_FILL * STEP_DEG <= TRAVEL_DEG,
              "stop table plus headroom runs past the calibrated travel");
static_assert(US_MIN_SAFE < US_MAX_SAFE, "servo pulse limits are inverted");

// PULSE is allowed outside the calibrated ends, because finding them is the whole
// point of it. This is the envelope no hobby servo should be driven past.
constexpr int US_HARD_MIN = 500;
constexpr int US_HARD_MAX = 2500;
static_assert(US_HARD_MIN <= US_MIN_SAFE && US_MAX_SAFE <= US_HARD_MAX,
              "calibrated ends must sit inside the commissioning envelope");

// ----- Motion profile -----
/*
 * 45 deg in 250 ms, which is well inside an MG90S's own 0.1 s / 60 deg and gentle
 * on both the coupling and the cell. SETTLE_MS then holds the target before the
 * tablet is allowed to start moving, so the gear train is never released while the
 * output is still creeping.
 *
 * DOSE_FALL_MS covers the tablet's trip from the chute geometry: about 44 mm of
 * fall onto the ramp, 65 mm of slide and the bounce in the tray, before the servo
 * is released and the host's vision check reads the tray.
 */
constexpr float SLEW_DEG_PER_S = 180.0f;
const unsigned long SETTLE_MS = 120;
const unsigned long DOSE_FALL_MS = 600;

enum class State : uint8_t {
  IDLE,
  MOVE,
  SETTLE,
  DOSE_FALL,
  COMPLETE
};

enum class Request : uint8_t {
  NONE,
  DISPENSE,
  REZERO,
  RESEAT,     // TRIM / JOG: same stop, new offset
  PULSE       // commissioning: a raw pulse, no stop involved
};

Servo servoCarousel;

State state = State::IDLE;
Request request = Request::NONE;
unsigned long stateStartedMs = 0;

uint8_t stopIndex = 0;          // 0 .. DOSES_PER_FILL
float parkTrimDeg = 0.0f;       // set by TRIM / JOG, RAM only
int8_t lastDir = 1;             // +1 after a forward move, -1 after a reverse one

// What the shaft was last told, as a pulse. Seeded to match the boot belief
// (stop 0, approached forwards) so the first ramp starts somewhere sensible
// without commanding anything. Microseconds rather than degrees because PULSE has
// to be able to ramp outside the calibrated ends.
int commandedUs = 0;
int lastUs = -1;
int pulseTargetUs = 0;

int moveFromUs = 0;
int moveToUs = 0;
unsigned long moveMs = 0;

String serialBuffer;

// ----- Angles -----

// Nominal shaft angle for a stop, before trim or play.
float stopDeg(uint8_t index) {
  return HEADROOM_DEG + static_cast<float>(index) * STEP_DEG;
}

// Where to put the SHAFT so the CAROUSEL ends up on the stop: it trails by the
// coupling's play in whichever direction the move is going.
float commandDeg(uint8_t index, int8_t dir) {
  return stopDeg(index) + parkTrimDeg + static_cast<float>(dir) * COUPLING_PLAY_DEG;
}

// Stop targets are clamped to the calibrated ends: a stop that needs more travel
// than the servo has is a calibration error, not something to drive into.
int usForDeg(float deg) {
  const float us = US_MIN_SAFE + deg * US_PER_DEG;
  if (us <= US_MIN_SAFE) return US_MIN_SAFE;
  if (us >= US_MAX_SAFE) return US_MAX_SAFE;
  return static_cast<int>(us + 0.5f);
}

float degForUs(int us) {
  return (us - US_MIN_SAFE) / US_PER_DEG;
}

int stopUs(uint8_t index, int8_t dir) {
  return usForDeg(commandDeg(index, dir));
}

// Only writes when the pulse actually changes, so ramping every loop costs
// nothing and the record of what was commanded stays readable.
void writeUs(int us) {
  commandedUs = us;
  if (us != lastUs) {
    lastUs = us;
    servoCarousel.writeMicroseconds(us);
  }
}

void detachServo() {
  // Fail-safe: release PWM to cut holding current / heat / battery drain. The
  // carousel is held by the servo's own gearing, not by the signal.
  servoCarousel.detach();
  lastUs = -1;
}

void enterState(State next) {
  state = next;
  stateStartedMs = millis();
}

bool stateElapsed(unsigned long durationMs) {
  return (millis() - stateStartedMs) >= durationMs;
}

void startRamp(int targetUs) {
  moveFromUs = commandedUs;
  moveToUs = targetUs;

  const int deltaUs = (moveToUs > moveFromUs) ? moveToUs - moveFromUs
                                              : moveFromUs - moveToUs;
  // The rate sets the duration, so a multi-step rezero takes that many steps'
  // worth without anyone multiplying anything.
  moveMs = static_cast<unsigned long>(deltaUs / US_PER_DEG / SLEW_DEG_PER_S * 1000.0f) + 20;

  servoCarousel.attach(PIN_CAROUSEL);
  writeUs(moveFromUs);
  enterState(State::MOVE);
}

void startMoveTo(uint8_t index, int8_t dir) {
  stopIndex = index;
  lastDir = dir;
  startRamp(stopUs(index, dir));
}

// Commissioning only: drive a pulse directly, then treat the magazine as spent so
// a stray DISPENSE cannot follow a hand-jogged position. REZERO or SETSTOP first.
void startPulse(int targetUs) {
  lastDir = (targetUs >= commandedUs) ? +1 : -1;
  stopIndex = DOSES_PER_FILL;
  startRamp(targetUs);
}

void finishCycle(const __FlashStringHelper *reply) {
  detachServo();
  enterState(State::IDLE);
  Serial.println(reply);
}

void reportStatus() {
  Serial.print(F("STATE="));
  Serial.print(static_cast<int>(state));
  Serial.print(F(" STOP="));
  Serial.print(static_cast<int>(stopIndex));
  Serial.print('/');
  Serial.print(static_cast<int>(DOSES_PER_FILL));
  Serial.print(F(" ANGLE="));
  Serial.print(degForUs(commandedUs), 2);
  Serial.print(F(" US="));
  Serial.print(commandedUs);
  Serial.print(F(" TRIM="));
  Serial.print(parkTrimDeg, 2);
  Serial.print(F(" DOSES="));
  Serial.println(static_cast<int>(DOSES_PER_FILL));
}

void reportCalibration() {
  Serial.print(F("CAL US="));
  Serial.print(US_MIN_SAFE);
  Serial.print(F(".."));
  Serial.print(US_MAX_SAFE);
  Serial.print(F(" TRAVEL="));
  Serial.print(TRAVEL_DEG, 1);
  Serial.print(F(" PLAY="));
  Serial.print(COUPLING_PLAY_DEG, 2);
  Serial.print(F(" TRIM="));
  Serial.print(parkTrimDeg, 2);
  Serial.print(F(" DOSES="));
  Serial.println(static_cast<int>(DOSES_PER_FILL));
}

// ----- Commands -----

String argumentOf(const String &verb) {
  const int space = verb.indexOf(' ');
  return (space > 0) ? verb.substring(space + 1) : String();
}

// toFloat()/toInt() read any non-number as 0, which would silently accept
// "TRIM x" as 0, so insist on something numeric first.
bool parseNumber(const String &arg, float &out) {
  if (arg.length() == 0) return false;
  const char c = arg[0];
  if (!isDigit(c) && c != '-' && c != '+' && c != '.') return false;
  out = arg.toFloat();
  return true;
}

void ackTrim() {
  Serial.print(F("ACK_TRIM "));
  Serial.println(parkTrimDeg, 2);
}

// Shared by TRIM (absolute) and JOG (relative): bound it, keep it, and re-seat the
// carousel on the stop it is already on so the change can be watched.
void applyTrim(float requested) {
  if (requested < -TRIM_RANGE_DEG || requested > TRIM_RANGE_DEG) {
    Serial.println(F("ERR_ARG"));
    return;
  }
  parkTrimDeg = requested;
  request = Request::RESEAT;
}

void handleCommand(const String &line) {
  String verb = line;
  verb.toUpperCase();

  if (verb == "DISPENSE") {
    if (state != State::IDLE) {
      Serial.println(F("ERR_BUSY"));
    } else if (stopIndex >= DOSES_PER_FILL) {
      // Refuse rather than step into the end of the travel and report a dose that
      // never fell. Refill, then REZERO.
      Serial.println(F("ERR_MAGAZINE_EMPTY"));
    } else {
      request = Request::DISPENSE;
    }
    return;
  }

  if (verb == "REZERO") {
    if (state != State::IDLE) {
      Serial.println(F("ERR_BUSY"));
    } else {
      request = Request::REZERO;
    }
    return;
  }

  if (verb.startsWith("SETSTOP")) {
    if (state != State::IDLE) {
      Serial.println(F("ERR_BUSY"));
      return;
    }
    float requested = 0.0f;
    if (!parseNumber(argumentOf(verb), requested) || requested < 0 ||
        requested > static_cast<float>(DOSES_PER_FILL)) {
      Serial.println(F("ERR_ARG"));
    } else {
      // Belief only: the carousel does not move, which is the whole point. The
      // commanded angle moves with it so the next ramp starts from the new belief.
      stopIndex = static_cast<uint8_t>(requested);
      commandedUs = stopUs(stopIndex, lastDir);
      Serial.println(F("ACK_SETSTOP"));
    }
    return;
  }

  if (verb.startsWith("TRIM")) {
    if (state != State::IDLE) {
      Serial.println(F("ERR_BUSY"));
      return;
    }
    float requested = 0.0f;
    if (!parseNumber(argumentOf(verb), requested)) {
      Serial.println(F("ERR_ARG"));
    } else {
      applyTrim(requested);
    }
    return;
  }

  if (verb.startsWith("JOG")) {
    if (state != State::IDLE) {
      Serial.println(F("ERR_BUSY"));
      return;
    }
    float delta = 0.0f;
    if (!parseNumber(argumentOf(verb), delta)) {
      Serial.println(F("ERR_ARG"));
    } else {
      applyTrim(parkTrimDeg + delta);
    }
    return;
  }

  if (verb.startsWith("PULSE")) {
    if (state != State::IDLE) {
      Serial.println(F("ERR_BUSY"));
      return;
    }
    float requested = 0.0f;
    if (!parseNumber(argumentOf(verb), requested) || requested < US_HARD_MIN ||
        requested > US_HARD_MAX) {
      Serial.println(F("ERR_ARG"));
    } else {
      pulseTargetUs = static_cast<int>(requested + 0.5f);
      request = Request::PULSE;
    }
    return;
  }

  if (verb == "PING") {
    Serial.println(F("PONG"));
    return;
  }

  if (verb == "STATUS") {
    reportStatus();
    return;
  }

  if (verb == "CAL") {
    reportCalibration();
    return;
  }

  Serial.println(F("ERR_UNKNOWN_CMD"));
}

void pollSerial() {
  while (Serial.available() > 0) {
    const char c = static_cast<char>(Serial.read());
    if (c == '\n' || c == '\r') {
      serialBuffer.trim();
      if (serialBuffer.length() > 0) {
        handleCommand(serialBuffer);
      }
      serialBuffer = "";
    } else if (serialBuffer.length() < 64) {
      serialBuffer += c;
    }
  }
}

void serviceStateMachine() {
  switch (state) {
    case State::IDLE:
      switch (request) {
        case Request::DISPENSE:
          startMoveTo(stopIndex + 1, +1);
          break;
        case Request::REZERO:
          // Sweeps back across every compartment emptied this fill. Safe only
          // because they are empty — which is why it is a separate command and
          // not something the sketch does on its own.
          startMoveTo(0, -1);
          break;
        case Request::RESEAT:
          startMoveTo(stopIndex, lastDir);
          break;
        case Request::PULSE:
          startPulse(pulseTargetUs);
          break;
        default:
          break;
      }
      break;

    case State::MOVE: {
      const unsigned long elapsed = millis() - stateStartedMs;
      if (elapsed >= moveMs) {
        writeUs(moveToUs);
        enterState(State::SETTLE);
      } else {
        const float f = static_cast<float>(elapsed) / static_cast<float>(moveMs);
        const float us = moveFromUs + (moveToUs - moveFromUs) * f;
        writeUs(static_cast<int>(us + 0.5f));
      }
      break;
    }

    case State::SETTLE:
      if (stateElapsed(SETTLE_MS)) {
        // Nothing falls during a rezero or a re-seat — a rezero only crosses
        // compartments already emptied, and a re-seat barely moves — so only a
        // dose waits for the tablet.
        enterState(request == Request::DISPENSE ? State::DOSE_FALL
                                                : State::COMPLETE);
      }
      break;

    case State::DOSE_FALL:
      if (stateElapsed(DOSE_FALL_MS)) {
        enterState(State::COMPLETE);
      }
      break;

    case State::COMPLETE: {
      const Request done = request;
      request = Request::NONE;
      switch (done) {
        case Request::REZERO:
          finishCycle(F("ACK_REZERO"));
          break;
        case Request::RESEAT:
          detachServo();
          enterState(State::IDLE);
          ackTrim();
          break;
        case Request::PULSE:
          detachServo();
          enterState(State::IDLE);
          Serial.print(F("ACK_PULSE "));
          Serial.println(commandedUs);
          break;
        default:
          finishCycle(F("ACK_DISPENSE"));
          break;
      }
      break;
    }

    default:
      break;
  }
}

void setup() {
  Serial.begin(115200);
  while (!Serial && millis() < 3000) {
    // Non-blocking wait for USB serial host; continue after timeout for BLE-only use later.
  }
  // Deliberately no move here: the servo already holds the carousel wherever it
  // was left, and writing an angle now could sweep full compartments across the
  // opening and dump them.
  commandedUs = stopUs(0, lastDir);
  detachServo();
  enterState(State::IDLE);
  Serial.println(F("READY_PILL_DISPENSER"));
  reportCalibration();
}

void loop() {
  pollSerial();
  serviceStateMachine();
  // No delay() — loop stays responsive for serial / future BLE.
}

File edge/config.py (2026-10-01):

"""Shared edge configuration for vision, serial, and telemetry."""

from __future__ import annotations

from pathlib import Path

# Camera
CAMERA_INDEX = 1
FRAME_WIDTH = 1280
FRAME_HEIGHT = 720

# Face gate (MediaPipe Face Detection)
FACE_MIN_CONFIDENCE = 0.65
FACE_STABLE_FRAMES = 8  # consecutive frames before allowing dispense

# Pill verification (OpenCV) — tune for your candy / lighting
# Fractions of the camera frame. The catch tray, plus about an inch of
# margin on every side. The tray sits left of the laptop and in front of
# the carousel; 0.87 put the box on the keyboard.
PILL_ROI_X0 = 0.12
PILL_ROI_X1 = 0.37
PILL_ROI_Y0 = 0.76
PILL_ROI_Y1 = 0.99
# Colored candy still matches this range. White capsules do not: their
# saturation is near 0, so the room was counted and the pills were not.
PILL_HSV_LOWER = (0, 40, 40)
PILL_HSV_UPPER = (179, 255, 255)
PILL_WHITE_HSV_LOWER = (0, 0, 200)
PILL_WHITE_HSV_UPPER = (179, 45, 255)
PILL_MIN_AREA = 80
PILL_MAX_AREA = 8000
PILL_EXPECTED_COUNT = 1
PILL_VERIFY_TIMEOUT_S = 3.0

# Serial / mock hardware
SERIAL_BAUD = 115200
SERIAL_PORT = ""  # e.g. "/dev/ttyACM0" or "COM3"; empty = auto-skip to mock
MOCK_DISPENSE_LATENCY_MS = 350
DISPENSE_COMMAND = "DISPENSE\n"
ACK_TOKEN = "ACK_DISPENSE"
RETRY_LIMIT = 2

# Telemetry
PATIENT_ID = "patient_demo_001"
TELEMETRY_DIR = Path(__file__).resolve().parent / "logs" / "telemetry"

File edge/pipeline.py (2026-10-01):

"""
End-to-end edge pipeline (software-first):

  Face presence -> hardware DISPENSE (serial or mock) -> pill verify -> telemetry JSONL

Usage:
  python pipeline.py --mode mock
  python pipeline.py --mode serial --port /dev/ttyACM0
  python pipeline.py --mode mock --headless   # single-shot using camera if available
"""

from __future__ import annotations

import argparse
import logging
import sys
import time

import cv2
import numpy as np

from config import CAMERA_INDEX, FRAME_HEIGHT, FRAME_WIDTH, RETRY_LIMIT
from face_gate import FaceGate
from hardware_bridge import HardwareBridge
from pill_verify import PillVerifier, latest_frame
from telemetry import TelemetryWriter, build_event

logging.basicConfig(
    level=logging.INFO,
    format="%(asctime)s %(levelname)s [%(name)s] %(message)s",
)
logger = logging.getLogger("pipeline")

WINDOW = "Pill Dispenser Edge (q=quit)"


def _capture_backends() -> list[tuple[int, str]]:
    """DirectShow first on Windows. The default MSMF backend often reports a closed camera."""
    if sys.platform == "win32" and hasattr(cv2, "CAP_DSHOW"):
        return [(cv2.CAP_DSHOW, "dshow"), (cv2.CAP_ANY, "default")]
    return [(cv2.CAP_ANY, "default")]


def try_open_camera(index: int = CAMERA_INDEX) -> cv2.VideoCapture | None:
    """Open a camera, releasing any backend that does not actually start."""
    for backend, name in _capture_backends():
        try:
            capture = cv2.VideoCapture(index, backend)
        except Exception:
            logger.exception("Camera index %s failed to open via %s", index, name)
            continue
        if capture.isOpened():
            capture.set(cv2.CAP_PROP_BUFFERSIZE, 1)
            capture.set(cv2.CAP_PROP_FRAME_WIDTH, FRAME_WIDTH)
            capture.set(cv2.CAP_PROP_FRAME_HEIGHT, FRAME_HEIGHT)
            logger.info("Camera index %s opened via %s", index, name)
            return capture
        capture.release()
        logger.info("Camera index %s did not open via %s", index, name)
    return None


def open_camera(index: int = CAMERA_INDEX) -> cv2.VideoCapture:
    capture = try_open_camera(index)
    if capture is None:
        raise RuntimeError(
            f"Camera index {index} could not be opened. "
            "Allow desktop apps to use the camera, and close anything else that has it."
        )
    return capture


def annotate(frame, face_result, pill_result, status: str):
    if face_result.box is not None:
        x, y, w, h = face_result.box
        color = (40, 200, 40) if face_result.stable else (40, 180, 220)
        cv2.rectangle(frame, (x, y), (x + w, y + h), color, 2)
        cv2.putText(
            frame,
            f"face {face_result.confidence:.2f}",
            (x, max(20, y - 8)),
            cv2.FONT_HERSHEY_SIMPLEX,
            0.6,
            color,
            2,
        )

    x0, y0, x1, y1 = PillVerifier.roi_bounds(frame)
    cv2.rectangle(frame, (x0, y0), (x1, y1), (220, 180, 40), 1)
    cv2.putText(frame, status, (20, 30), cv2.FONT_HERSHEY_SIMPLEX, 0.7, (240, 240, 240), 2)
    if pill_result is not None:
        cv2.putText(
            frame,
            f"pills={pill_result.count} match={pill_result.matched}",
            (20, 60),
            cv2.FONT_HERSHEY_SIMPLEX,
            0.65,
            (240, 240, 240),
            2,
        )
        # Contours are in tray-ROI coordinates. Draw them back on the full frame.
        origin_x, origin_y = x0, y0
        for x, y, bw, bh in pill_result.contours:
            cv2.rectangle(
                frame,
                (origin_x + x, origin_y + y),
                (origin_x + x + bw, origin_y + y + bh),
                (40, 220, 220),
                2,
            )
    return frame


def settle_camera(capture: cv2.VideoCapture, frames: int = 15) -> None:
    """Show the first frames instead of counting a face against a black image.

    Laptop cameras spend the first part of a second settling exposure. Those
    frames used to be the ones the face gate was waiting on, which is the slow
    startup before the first dispense.
    """
    started = time.perf_counter()
    shown = 0
    for _ in range(frames):
        ok, frame = capture.read()
        if not ok or frame is None:
            continue
        shown += 1
        cv2.putText(
            frame,
            "Camera settling...",
            (20, 40),
            cv2.FONT_HERSHEY_SIMPLEX,
            0.8,
            (240, 240, 240),
            2,
        )
        cv2.imshow(WINDOW, frame)
        cv2.waitKey(1)
    logger.info(
        "Camera settled in %s ms (%s frames)",
        int((time.perf_counter() - started) * 1000),
        shown,
    )
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

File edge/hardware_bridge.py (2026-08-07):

"""Serial bridge to Arduino Nano 33 BLE with automatic mock fallback."""

from __future__ import annotations

import logging
import time
from dataclasses import dataclass
from typing import Literal

import serial
from serial.tools import list_ports

from config import ACK_TOKEN, DISPENSE_COMMAND, SERIAL_BAUD, SERIAL_PORT
from mock_arduino import MockArduino, MockSerialResponse

logger = logging.getLogger(__name__)

HardwareMode = Literal["serial", "mock"]


@dataclass
class DispenseCommandResult:
    ok: bool
    message: str
    latency_ms: int
    mode: HardwareMode


class HardwareBridge:
    def __init__(
        self,
        port: str = SERIAL_PORT,
        baud: int = SERIAL_BAUD,
        force_mock: bool = False,
        timeout_s: float = 2.0,
    ) -> None:
        self.port = port
        self.baud = baud
        self.timeout_s = timeout_s
        self._serial: serial.Serial | None = None
        self._mock: MockArduino | None = None
        self.mode: HardwareMode = "mock"

        if force_mock:
            self._mock = MockArduino()
            self.mode = "mock"
            logger.info("HardwareBridge forced into mock mode")
            return

        opened = self._try_open_serial()
        if not opened:
            self._mock = MockArduino()
            self.mode = "mock"
            logger.warning("No Arduino serial port found; using MockArduino")

    def _try_open_serial(self) -> bool:
        candidates: list[str] = []
        if self.port:
            candidates.append(self.port)
        else:
            for item in list_ports.comports():
                desc = f"{item.device} {item.description} {item.manufacturer}".lower()
                if any(token in desc for token in ("arduino", "nano", "usb serial", "ttyacm", "ttyusb")):
                    candidates.append(item.device)

        for candidate in candidates:
            try:
                self._serial = serial.Serial(candidate, self.baud, timeout=self.timeout_s)
                time.sleep(1.5)  # Nano soft-reset settle
                self._serial.reset_input_buffer()
                self.port = candidate
                self.mode = "serial"
                logger.info("Opened Arduino serial on %s @ %s", candidate, self.baud)
                return True
            except Exception:
                logger.exception("Failed opening serial port %s", candidate)
                self._serial = None
        return False

    def dispense(self) -> DispenseCommandResult:
        if self.mode == "mock":
            assert self._mock is not None
            response: MockSerialResponse = self._mock.send_dispense()
            return DispenseCommandResult(
                ok=response.ok,
                message=response.message,
                latency_ms=response.latency_ms,
                mode="mock",
            )

        assert self._serial is not None
        started = time.perf_counter()
        try:
            self._serial.reset_input_buffer()
            self._serial.write(DISPENSE_COMMAND.encode("utf-8"))
            self._serial.flush()
            line = self._serial.readline().decode("utf-8", errors="replace").strip()
            latency_ms = int((time.perf_counter() - started) * 1000)
            ok = ACK_TOKEN in line
            return DispenseCommandResult(ok=ok, message=line or "NO_RESPONSE", latency_ms=latency_ms, mode="serial")
        except Exception as exc:
            latency_ms = int((time.perf_counter() - started) * 1000)
            logger.exception("Serial dispense command failed")
            return DispenseCommandResult(ok=False, message=str(exc), latency_ms=latency_ms, mode="serial")

    def close(self) -> None:
        try:
            if self._serial is not None and self._serial.is_open:
                self._serial.close()
        except Exception:
            logger.exception("Error closing serial port")
        if self._mock is not None:
            self._mock.close()

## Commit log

2026-08-07 Add MedTech lead architect expert agent and project scaffold
    Encode the Lead Technical Co-Developer persona as a Cursor subagent
    with project schedule/BOM context, always-on rules, AGENTS.md, and
    Week 1–6 directory layout for the pill dispenser prototype.
2026-08-07 Add software-first edge, firmware, and local medallion track
    Enable pre-hardware development: mock serial pipeline, MediaPipe/OpenCV
    edge modules, compile-ready Nano 33 BLE firmware, synthetic Bronze->Gold
    transforms, and a no-hardware roadmap.
    [silver_dispense_events.csv]
2026-08-07 Containerize software-first stack with Docker Compose
    Add Dockerfile, compose services, entrypoint dispatcher, and docs so
    edge mock smoke and local Bronze→Silver→Gold run in one image without
    host Python setup. Optional camera/serial profiles for later hardware.
2026-08-18 Add Arduino toolchain verify scripts (compile without board)
    Provide bash and PowerShell helpers that use arduino-cli to compile
    pill_dispenser for Nano 33 BLE without requiring USB hardware.
2026-08-18 Add CAD embedded-hardware subagent for STL/OpenSCAD parts
    Introduce /cad-embedded-hardware for parametric carousel, latch, and
    Nano/MG90S/LiPo housing design, plus cad/ layout and shared parameters.
    [parameters.scad]
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2026-08-18 Add explorables OpenSCAD housing, carousel, and latch examples
    Provide parametric Parts A–D, exploded assembly preview, exported STL
    meshes, and PNG previews so mechanical packaging can be studied before
    print.
    [assembly_preview.scad, assembly_preview.stl, parameters.scad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]
2026-08-18 Generate full CAD prototype print set with STLs and previews
    Add lid, catch tray, spout, latch bracket, clips, feet, and pocket
    inserts; refresh assembly preview; export STL/PNG for parts A–K via
    render_all.sh for an adequate mechanical prototype.
    [assembly_preview.scad, assembly_preview.stl, parameters.scad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]
2026-09-04 Separate multi-body D/I/J STLs into single-part files
    Export Part D gate and arm as individual STLs, and ship one clip and
    one foot mesh each so slicers no longer see floating multi-body plates.
    [assembly_preview.stl, part_a_base_enclosure.stl, part_b_base_plate.stl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]
2026-09-09 Fix camera face detection with MediaPipe Tasks and OpenCV 4 pin
    Replace legacy mp.solutions FaceDetection with Tasks BlazeFace model,
    vendor the short-range TFLite, constrain OpenCV to 4.x (avoid OpenCV 5
    Haar gap), and add libEGL for MediaPipe in Docker.
    [face_gate.py]
2026-09-17 Add v2 carousel-only CAD set: keyed fixed plate, direct drive, wide chute
    [assembly_preview_v2.scad, lib_v2.scad, parameters_v2.scad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]
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2026-09-17 Model v3 geometry: integral deck, 8 open bins, single-servo direct drive
    Implements the reference drawing rather than the gate variants in the earlier
    plan. The park convention (the just-emptied compartment rests over the discharge
    wedge) makes a shutter unnecessary, so the compartments stay open bins with no
    floor as drawn.
    - housing splits at the deck plane so both halves print support-free
    - 24 deg wedge vs 36.4 deg compartment interior gives +/- 6.2 deg park margin,
    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
    [assembly_preview_v3.scad, lib_v3.scad, parameters_v3.scad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]
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2026-09-17 Move v3 previews to previews/ and reframe the part renders
    - folder renamed to previews/ to match the v1 and v2 sets
    - each part gets an explicit look-at point and distance: the parts sit in
    assembly coordinates, so --viewall framed the bracket at a fraction of the
    frame and hid the deck's discharge wedge
    - adds two detail views: straight down the deck wedge, and the chute running out
    through the wall notch
    - widens the wall notch 0.4 mm past the chute's inside width so their faces are
    no longer coplanar
    - render_all_v3.sh builds the annotated hero too, when Pillow is available
    [parameters_v3.scad]
2026-09-18 cad/v3: make the chute ramp continuous through the wall notch
    The notch through the drum wall was a plain box, which sliced the ramp out
    exactly where it passes through the wall and left a hole a tablet dropped
    through into the electronics bay. Cut it as a box minus the chute solid
    instead, so the subtraction can only ever remove housing wall.
    Also start the ramp at y=14, inside the wedge's 16 mm inner radius, so a
    tablet lands on ramp rather than on its leading edge; keep a hoop strip of
    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
    [assembly_preview_v3.scad, check_drop_path.scad, parameters_v3.scad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]
2026-09-18 cad/v3: give every part file its print orientation
    D3 already applied a print flip at its top-level call while its module stayed
    in assembly coordinates. Follow that convention for the rest: A3 drops to the
    deck's underside, and E3 flips onto its flange plane, where the pad, arm and
    servo plate tops are coplanar and form one flat footprint. STL exports now
    load onto the bed ready to slice.
    Laying E3 out flat also exposed a rib that hung 1.5 mm off one edge of the
    arm — an unsupported flange, and stiffer on one side than the other. Both
    ribs now sit inside the arm's width.
    [part_a3_deck_body.scad, part_e3_servo_bracket.scad]
2026-09-18 cad/v3: re-render previews and export the seven part STLs
    All seven meshes are watertight (no unpaired edges, no degenerate facets).
    [part_a3_deck_body.stl, part_b3_base_body.stl, part_c3_carousel.stl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]
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2026-09-18 cad/v3: add the three test coupons
    C1 proves the running and sweep gaps, C2 the three drive-train fits, C3 the
    chute-to-tray dock. Each is cut out of the real parts with an intersection
    rather than modelled again, so they carry the real dimensions and cannot drift
    from them, and each file's header says what to look for and which parameter to
    change when it fails.
    Together they are about 90 minutes of printing ahead of the 24 hours that A3,
    B3 and C3 take, and they cover the fits a render cannot prove.
    [coupon_1_sector.scad, coupon_2_drive_train.scad, coupon_3_chute_dock.scad]
2026-09-18 cad/v3: render and export the coupons
    [coupon_1_sector.stl, coupon_2_drive_train.stl, coupon_3_chute_dock.stl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]
2026-09-18 firmware: drive the v3 mechanism — one positional servo, absolute stops
    The sketch was still on the v1 design: a carousel servo that wrote 45 deg and
    came straight back to 0, plus a latch servo on D10. v3 has no latch (the deck
    parks the emptied compartment over the opening) and needs absolute stops, since
    parking has only +/- 6.2 deg of margin before the opening starts draining the
    next compartment.
    The consequence is worth stating plainly rather than discovering: a 180 deg
    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
2026-09-18 docs: drop the latch from the project-level docs
    v3 replaced it with the carousel's park position, so the architecture table,
    the BOM note and the Week 1 plan were describing hardware that is no longer
    in the design.
2026-09-18 firmware: add a host harness for the dispense state machine
    Compiles the sketch on a PC against a fake clock, a fake serial port and a
    recording Servo, then drives it through the sequences that matter: four doses at
    45, 90, 135 and 180 deg, the refusal after them, the rezero held for its whole
    four-step sweep, and a boot that commands no angle.
    Those are behaviours, not compile errors — the alternative way to catch them is
    watching tablets fall into the wrong place. Needs only g++, so it runs before
    any hardware arrives and alongside the existing toolchain check.
    [host_harness.cpp]
2026-09-18 cad/v3: correct the chute callout on the annotated hero
    It described the wall notch opening from the deck down; what matters now is
    that the ramp itself is unbroken.
2026-09-19 cad/v3: add previews that show the chute is continuous
    The preview set described the fix but did not show it: the closest view was a
    part-level detail looking down into the drum, where the ramp's path through the
    wall notch is hard to read.
    Two views now carry it. v3_chute.png closes the half section in on the chute, so
    the ramp reads as one unbroken line from under the deck's wedge to the lip over
    the tray, with the dose riding it. v3_drop_path.png ghosts the volume a tablet
    can fall through over the base body, which is the check in check_drop_path.scad
    rendered rather than described.
2026-09-20 cad/v3: lift the servo bracket clear of the carousel sweep
    The bracket's wall pad started at z 72 and stood 6 mm off the bore, so a
    26 x 10.6 x 11.35 mm block of it sat inside the ring the dividers sweep
    (z 57.35 to 83.35, out to r 56.3). All eight dividers would have hit it:
    the carousel could not have turned at all.
    The pad and gusset are now derived off car_top instead of being typed in,
    and the drum wall runs to z 106 so both M3 wall screws still land in wall
    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
    [check_carousel_clearance.scad, coupon_1_sector.stl, coupon_2_drive_train.stl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]
2026-09-20 cad/v3: size the coupling for the park margin, document the torque budget
    Torque was never the question: worst case demand is 31 mN.m (thrust
    friction on the pilot post, 40 g of tablets ploughing on the deck at a
    35 mm mean radius, and the carousel's 8.7e-5 kg.m2 through 45 deg), against
    177 mN.m from an MG90S at 4.8 V -- 5.8x, and still 3x for a derated clone
    on the bare 3.7 V cell. PLAN.md section 13 carries the budget.
    The error budget was the question. The hex is loose on purpose, and a step
    ends with its driving flats in contact, so the carousel parks behind its
    stop by the full play. At 7 mm A/F and 0.4 mm slip that is +/- 6.28 deg --
    the entire +/- 6.2 deg park margin, before the ser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
    [coupon_1_sector.stl, coupon_2_drive_train.stl, coupon_3_chute_dock.stl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]
2026-09-20 firmware: command pulses, ramp the moves, and make the park trim usable
    The sketch was on the v3 mechanism but not on its error budget. Three
    things spend the +/- 6.2 deg park margin and it managed none of them.
    Assembly can only index the carousel in 17.1 deg horn teeth, 60 deg hex
    seatings and 90 deg horn screws, so up to 8.6 deg of park offset has to
    come out in firmware -- yet PARK_TRIM_DEG was pinned to 0, because stops
    at 0/45/90/135/180 used the servo's whole nominal span and the assert
    refused anything more. Angles now go out as pulse widths against measured
    endpoints (write() quantises to 1 deg, about 10 us, and pins the range to
    the core's 544-2400 mapping), the trim is a runtime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
    [coupon_1_sector.stl, coupon_2_drive_train.stl, coupon_3_chute_dock.stl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]
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2026-09-20 docs: wire the servo's 5V from the LiPo through the boost module
    The BOM left the servo supply as an open question; the boost module answers it.
    Records the chain, why the TP4056 stays in it, and what to do if the module sags
    under a step.
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2026-09-25 edge: add a wiggle mode for first contact with the servo
    The default run steps a full 45 deg immediately, which is a lot to ask of wiring
    nobody has powered before. --wiggle moves a few degrees either side of centre so a
    missing ground or a sagging supply shows up before anything can be thrown.
    [bench_servo.py]
2026-09-25 docs: commission the servo without a multimeter
    Silkscreen and a cool module replace the VO reading; stuttering, buzzing or a USB
    drop mid-move replace the under-load voltage check.
2026-09-25 edge: rezero before the turn check when the magazine is spent
    --wiggle leaves STOP at the magazine end on purpose; the default run was then
    failing on the first DISPENSE. Recover that state first so the fill can follow.
    [bench_servo.py]
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2026-09-25 docs: drop the meter reading from the wiring diagram legend
    The commissioning steps no longer assume a multimeter, so the legend should not
    either: cool boards and a wiggle stand in for a voltage.
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2026-09-25 edge: make --ends record only pulses that moved the horn
    Holding Enter ran the hunt into the 500-2500 us envelope and printed those
    limits as the servo's stops. A blank line no longer counts; each step asks
    whether the horn moved, and dial readings typed at the two ends become
    TRAVEL_DEG and a three-or-four dose answer.
    [bench_servo.py]
2026-09-25 edge: tell a buzzing horn from one that jumped backwards
    Buzzing in place is the mechanical stop, and a jump the other way means the
    pulse went past the feedback pot. --ends now asks which happened, and q keeps
    the previous pulse instead of driving further into the gears.
    [bench_servo.py]
2026-09-25 edge: check each dose is exactly one bin
    --dump rezeros, then dispenses one dose at a time and compares the dial
    reading with the move the park budget calls for: 45 deg on the carousel,
    and 45 plus twice the coupling play on the horn for the first dose only.
    A step that is short every time is the pulse scale, which JOG cannot fix.
    [bench_servo.py]
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2026-09-29 edge: insert each dispense event into a Databricks Bronze table
    The pipeline only appended a local JSONL file. With a workspace host, token,
    and SQL warehouse set, the same row is inserted as the dose is logged. A
    warehouse error is logged and does not stop the dispense.
    [databricks_sink.py, telemetry.py, test_databricks_sink.py]
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2026-09-29 edge: resolve the catalog that holds pill_dispenser.bronze_dispense_events
    The warehouse default is main, and that schema has no bronze table. Look the table up and insert the latest logged dispense event there.
    [databricks_sink.py, test_databricks_sink.py]
2026-09-29 edge: insert into pill_dispenser on the Hive Metastore
    The SQL editor shows the schema as pill_dispenser. The warehouse API was prefixing main and missing the table.
    [databricks_sink.py, test_databricks_sink.py]
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2026-09-30 databricks: add a 30-day bronze history for patient_demo_001
    Sixty morning and evening doses, late drift in the second half, then refresh Silver, Gold, and a dashboard view.
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2026-10-01 databricks: extend bronze history to three months
    Replace the 30-day series with 1 Jul–29 Sep 2026. Most doses are taken; 17 of 182 are missed on an irregular pattern.
2026-10-01 databricks: show ten missed August doses as gaps in the event counts
    Both doses on 10–14 Aug stay out of bronze_dispense_events so weekly and monthly counts drop, and dashboard_daily keeps those days at zero.
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2026-10-01 edge: count white capsules inside the catch tray
    The old color range matched the room and skipped the white pills, so a tray-sized box counted nothing. The tray crop and a bright low-saturation range now find those capsules.
    [config.py, pill_verify.py, pipeline.py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]
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
